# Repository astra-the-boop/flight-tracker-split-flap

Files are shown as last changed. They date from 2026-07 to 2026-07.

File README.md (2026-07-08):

# Split flap flight-tracker display
---
## Images
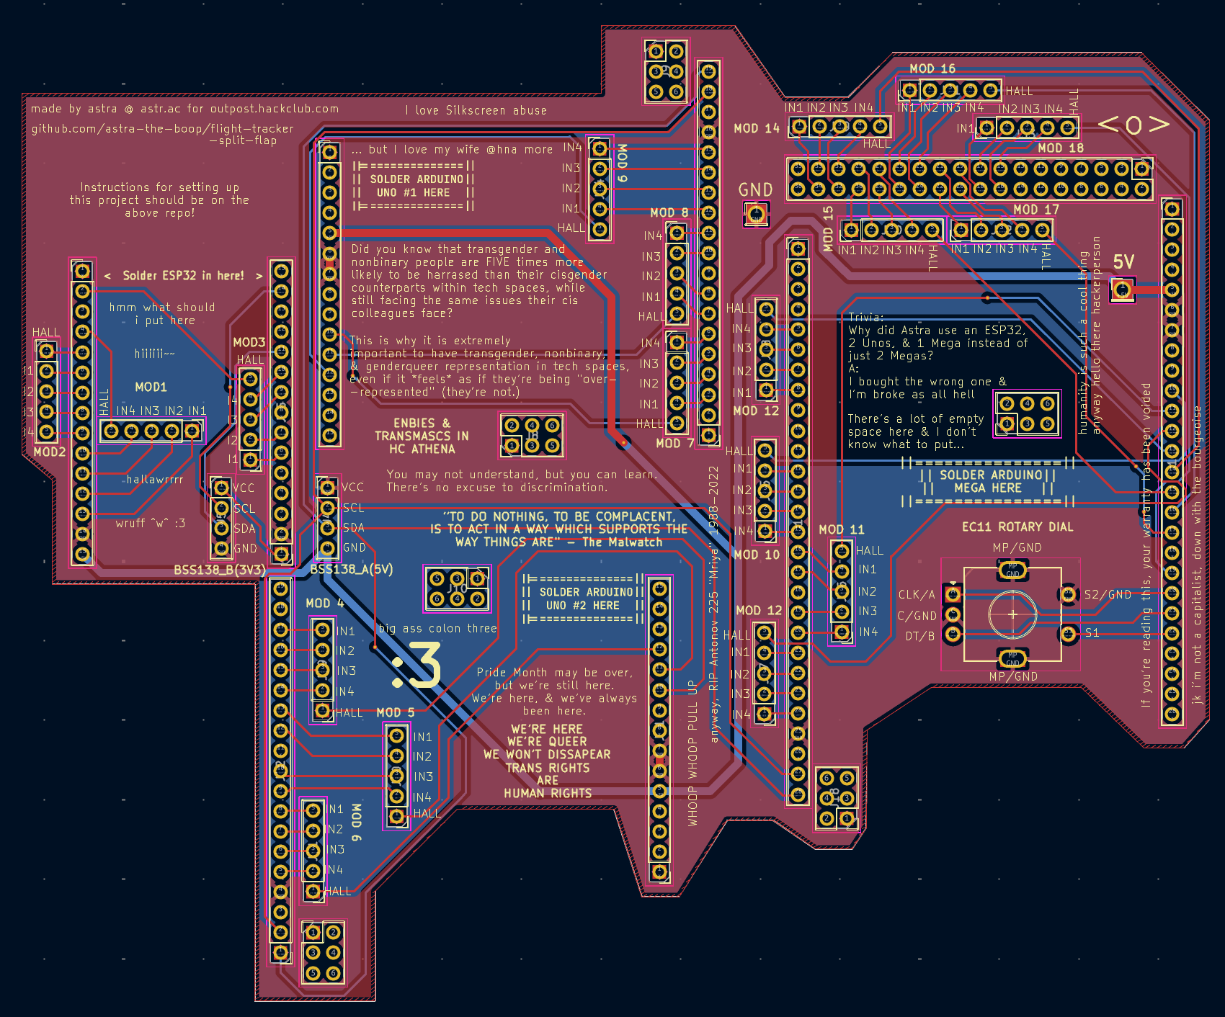
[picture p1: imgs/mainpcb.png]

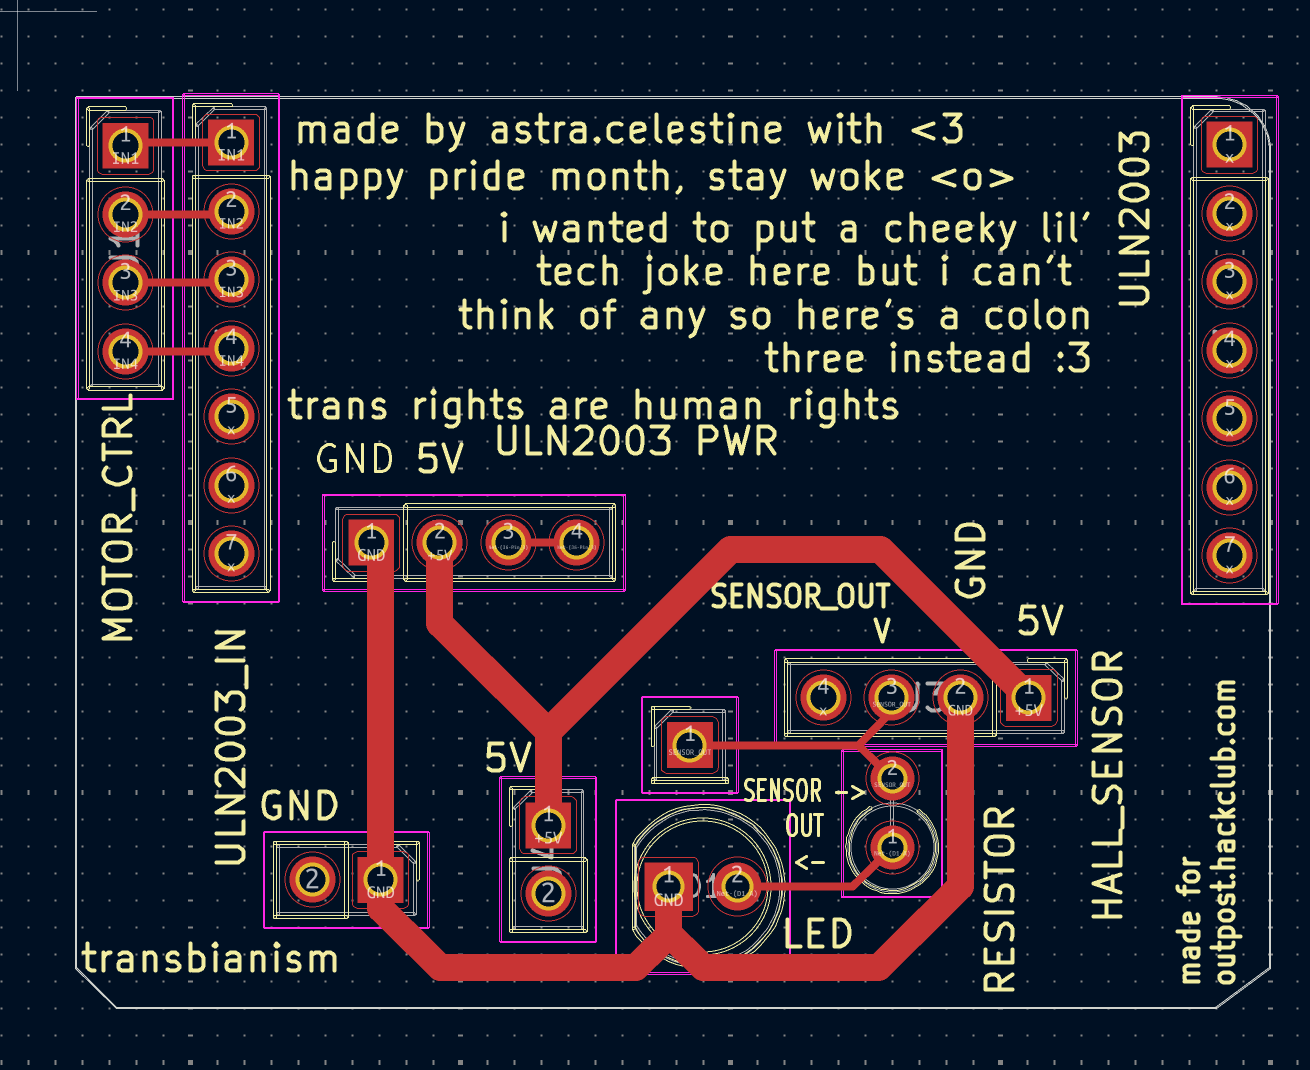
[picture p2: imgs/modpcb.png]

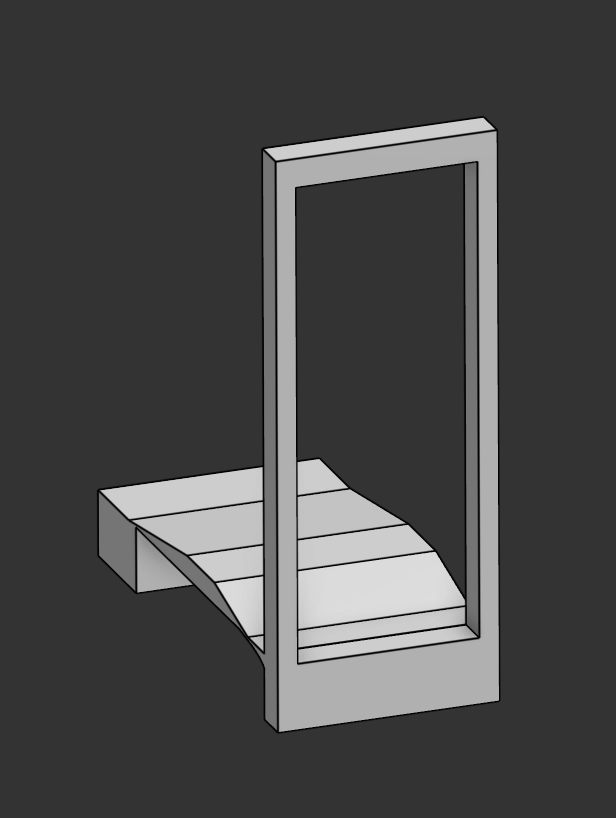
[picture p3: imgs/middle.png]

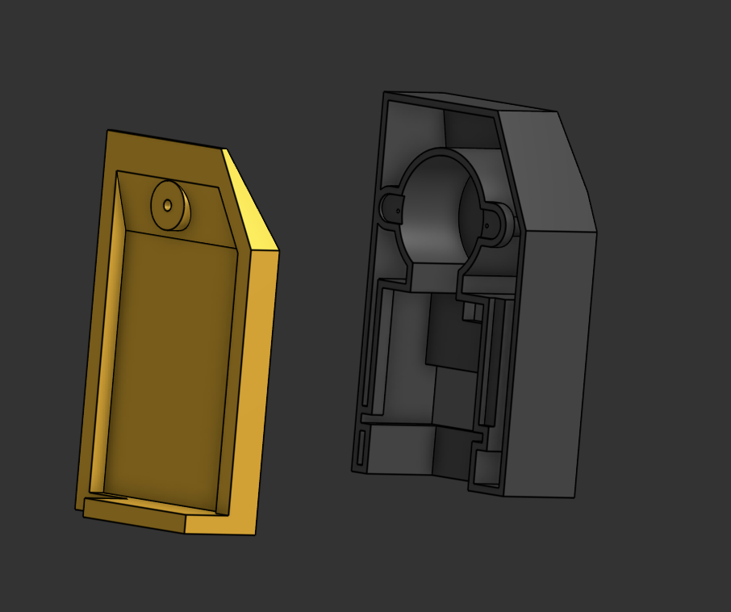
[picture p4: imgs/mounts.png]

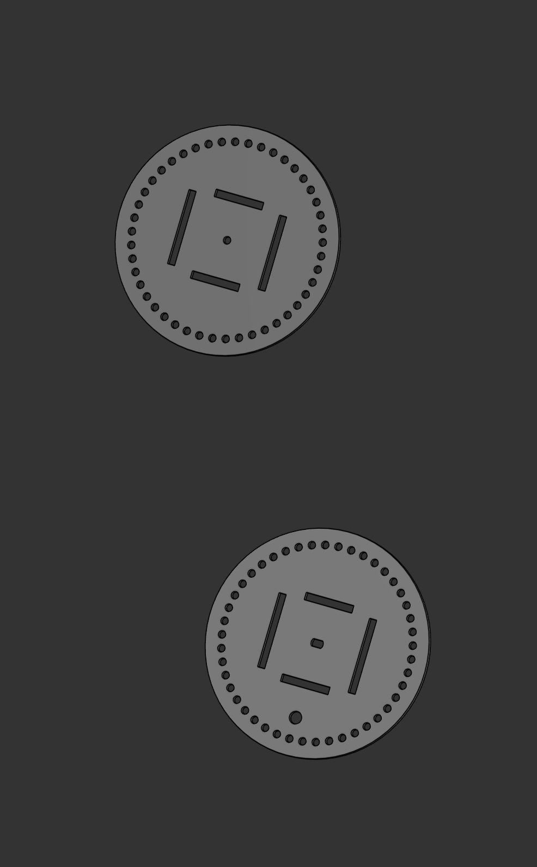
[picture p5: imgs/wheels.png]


## Whots this UwU?
It's a split flap display with 18 characters designed to show just enough info to track flights. It uses an ESP32 to send API requests to [AviationStack](https://docs.apilayer.com/aviationstack/docs/api-documentation) (oof, only 100 req/mo), and displays the info accordingly.

The display has 3 rows, the first row has 7 characters (1 showing logos, 2 showing airline IATA code, 4 showing flight number), the 2nd row has 6 characters showing the origin and destination airport, the 3rd row has 5 alphanumeric characters and shows flight status (INFLT, DELAY, CNCLD, BRDNG), or time (23:59, 5 DAYS, 5 HRS, 3H49M, etc) which could be configured to different modes (only show status, only show time, or switch between the two).

Each character is its own module and can function independently with 45 character positions each, and the PCB designs makes this simple to do. Each module also includes a magnet and a hall effect sensor for calibration.

## Dimensions
Each module by itself is 9cm wide, up to 14.5cm tall, and up to 10cm thick.
The entire system is 64.3cm wide, 47cm tall, and 15cm thick.

## CAD & PCB
This was designed in Onshape and KiCad.

## Other details:
This uses 1 ESP32 DevKit v1, 2 Arduino Unos, and 1 Arduino Mega. This is not the best way to do it, I only did this because I'm dead broke and that's what i had.
This project uses the MIT License.

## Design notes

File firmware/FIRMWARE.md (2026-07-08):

# Firmware
> ## Waiting to complete firmware code until I have the required hardware so this is completely untested, but here's a complete rundown of the code's logic:

## Module level:
The module has 4 input pins (INPUT1-4) relevant for controlling the motors. It also has 1 Hall effect sensor output pin, and a 5V and GND pin connected to the power supply (irrelevant to code).



Modules 1-3 is controlled and connected to the ESP32
Modules 4-6 is controlled by Arduino Uno 1, 7-9 is controlled by Uno 2.
Modules 10-18 are controlled by the Arduino Mega.

Where the 5 pins are connected to and where each module should be soldered to are labeled on the Main PCB's silkscreen (MOD*), (HALL is the hall effect sensor's input, IN1-4 is INPUT1-4).



## Retrieving data
The ESP32 sends RESTful GET requests to [AviationStack](https://aviationstack.com/)'s [/v1/timetable](https://docs.apilayer.com/aviationstack/docs/aviationstack-api-v-1-0-0#/default/getFlightSchedule) endpoint for the saved flight code. (Note: Free version is limited to 100 req/mo)
This uses the HTTPClient library (dependencies: Wifi.h, HTTPClient.h, WifiClientSecure.h, ArduinoJson.h)

## Parsing
As shown in README.md, there's 18 characters.
Char 1 (Logo): Have a set array of up to 44 of your most likely to be used airlines' IATA code (e.g. "CX"). From response["data"]["airline"]["iataCode"], search for that IATA code from the array, if found, return the index, else return 0 (blank).
Char 2 (IATA): response["data"]["airline"]["iataCode"][0]
Char 3: response["data"]["airline"]["iataCode"][1]
Char 4 (flight code): response["data"]["flight"]["number"][0]
Char 5-7: response["data"][... ...][1-3]
Char 8-10: response["data"]["departure"]["iataCode"][0-2]
Char 11-13: response...["arrival"][...][0-2]
Char 14-18: 
In case of showing time: response...["departure"]["scheduledTime"].substring(11,16) or response...["arrival"]... in if flight is already in air.
In case of showing flight status: Have 2 arrays of different statuses and the shortened version (e.g. ["boarding", "delayed", ...] ["BRDNG", "DELAY", ...]. Get response...["status"], get index of it in the first array, get the value of that index at the 2nd array.

Parse the value of that string substringed [0-5]

## Displaying
For the modules directly connected to the ESP32, the ESP32 uses AccelStepper to control the motors' position, movement, and acceleration. AccelStepper allows for simultanious commands while the default Stepper lib only allows for async execution.
The motor shall rotate until the hall effect sensor sends a signal (using INPUT_PULLUP), which then sets the index to 0. There shall be an array of characters (e.g. [BLANK/DEFAULT, A, B, C, ..., 8, 9, 0, -, :, " ", ...]) with 45 items, program starts a for loop until it reaches the desired character, for each loop, the motor rotates by 8º (AccelStepper allows for motor control by degrees), and increases the counter by 1.

For modules that aren't connected directly to the ESP32, the ESP32 shall send the desired character to be displayed to the Arduino Unos or Mega via I²C, and then it does the above.

## Input
There's a rotary encoder switch on the Arduino Mega, so the Mega shall receive input from the rotary encoder switch via INPUT_PULLUP, and relay it back to the ESP32 via I²C.
On the ESP32's memory, there shall be a string variable which represents the flight code.
By default, the displays show nothing, and the current mode is set to read only.
When a signal is received from the rotary encoder's CLK pin, Arduino mega starts a timer until it's released, if it's longer than 1500ms, then it relays a signal to the ESP32 to change to edit mode.
In edit mode, there is an index (pointer) variable set at 0 (representing flightCode[0] (the string we set earlier)). Rotating the encoder clockwise moves the value of the chracter of which the pointer is pointing to is set to the next item (or loops over to [0] if it's [-1]) of the array of characters we set earlier (blank, A-Z, 1-9, 0, special characters). Vice versa for counterclockwise. The motor moves 8º (or -8º for ccw) without checking for hall effect sensor homing.
Receiving a single click would move it to the next pointer position (or in case of [4], moves to [0]), a single click is a click where the timer ends <1500ms.
Once in edit mode and a long click (≥1500m) happens, all characters in flightCode.substr(2, 4) that is not either blank or an integer is replaced with '0' and if it's blank, it's replaced with '', and reformatted after such that it's a 4 digit number (e.g. 12 -> 0012). After which, a regular display reload would occur as described previously (i.e. does a rotation until sensor detects magnet, then rotate 8º until reaches the desired character). An API request to AviationStack would then be made and data is saved to request variable. After which it goes through the process of refreshing, requesting, parsing, and displaying as previously displayed.

## Refreshing
3 variables are set for the data refresh rates, one for 90 minutes until scheduled flight, one for 9 hours until scheduled flights, and one for all before that. (Would've just had everything at a really short refresh time if not for the fact that you only get like 100 FUCKING REQUESTS A MONTH FOR SOME REASON. IT'S THE BEST FUCKING OPTION TOO EVERYTHING ELSE IS PAID)
Just does a loop with the set time where each loop goes through the fetch-~~decode-execute~~parse-display cycle.

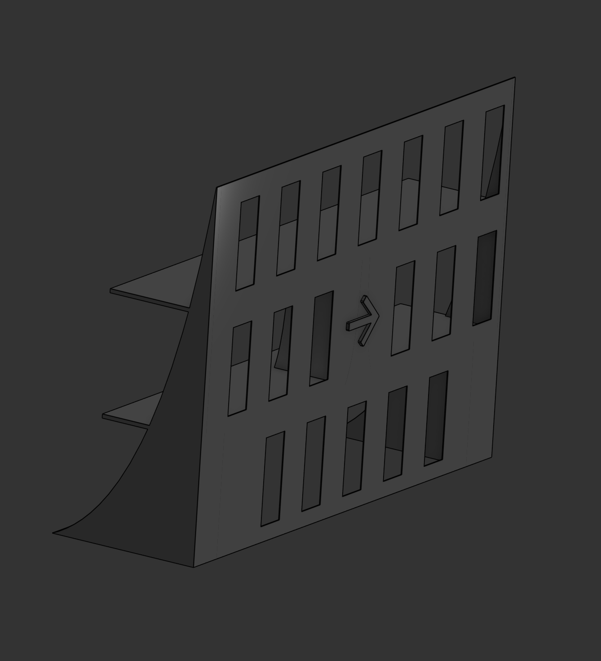
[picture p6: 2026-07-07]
imgs/shell.png

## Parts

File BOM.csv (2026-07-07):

Part | Qty | Price per pc VND | Price per pc USD | Total price USD | Link | Notes | SECTION
5V 28BYJ-48 Stepper motor + ULN2003 Module | 18 | 50,000 ₫ | $1.90 | $34.23 | https://vn.shp.ee/5EBNqvki |  | Modules
A3144 V1 Hall effect sensor MODULE | 18 | 25,000 ₫ | $0.95 | $17.12 | https://vn.shp.ee/HDDp57As
PCB | 1 | 300,000 ₫ | $11.41 | $11.41 |  | for all 18 modules (actually 25, they manufacturer gave me extra for some reason)
3D printing motor mount | 767.52 | 500 ₫ | $0.02 | $14.60 |  | per gram
3D printing wheel motor side | 252 | 500 ₫ | $0.02 | $4.79 |  | per gram
3D printing wheel right side | 261 | 500 ₫ | $0.02 | $4.96 |  | per gram
3D printing wheel connector 1+4 | 212.4 | 500 ₫ | $0.02 | $4.04 |  | per gram
3D printing wheel connector 2+3 | 293.76 | 500 ₫ | $0.02 | $5.59 |  | per gram
3D printing right side mount | 840.96 | 500 ₫ | $0.02 | $15.99 |  | per gram
3D printing centerpiece | 918 | 500 ₫ | $0.02 | $17.46 |  | per gram
2mm x Ø5mm Nd magnet (10pc) | 2 | 50,000 ₫ | $1.90 | $3.80 | https://vn.shp.ee/khDsGHYL
LEDs | 18 | 1,000 ₫ | $0.04 | $0.68
Resistor | 1 | 36,000 ₫ | $1.37 | $1.37 | https://vn.shp.ee/Kp1muEma
PCB | 1 | 440,000 ₫ | $16.74 | $16.74 |  |  | Main
5V/10A Power supply | 1 | 122,000 ₫ | $4.64 | $4.64
ESP32 | 1 | 136,000 ₫ | $5.17 | $5.17
Arduino Uno | 2 | 201,000 ₫ | $7.64 | $15.29 | https://vn.shp.ee/dqiFtsHQ
Arduino Mega | 1 | 280,000 ₫ | $10.65 | $10.65 | https://lkcg.vn/arduino-mega2560-ch340g-tang-kem-cap
EC11 Rotary Encoder Switch | 1 | 14,000 ₫ | $0.53 | $0.53 | https://banlinhkien.com/cong-tac-vo-cap-ec11-p6648261.html
BSS138 voltage thingy | 1 | 40,000 ₫ | $1.52 | $1.52 | https://hshop.vn/mach-chuyen-muc-ton-hieu-2-chieu-8-kenh | Including shipping
 |  |  | $0.00 | $0.00

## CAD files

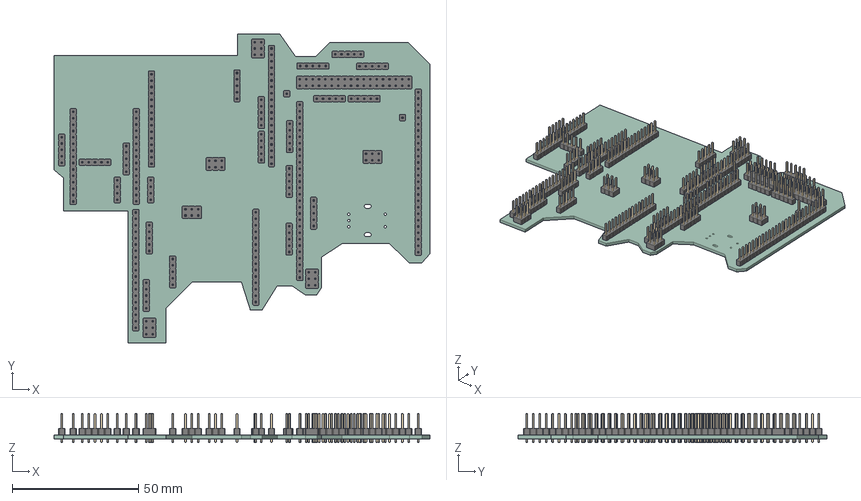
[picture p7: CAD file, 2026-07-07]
PCB/Main board.step
149.2 x 122.6 x 11.5 mm
PinHeader_1x05_P2.54mm_Vertical x 18
PinHeader_1x15_P2.54mm_Vertical x 4
PinHeader_1x19_P2.54mm_Vertical x 2
PinHeader_2x03_P2.54mm_Vertical x 6
PinHeader_1x04_P2.54mm_Vertical x 2
PinHeader_1x26_P2.54mm_Vertical
PinHeader_2x18_P2.54mm_Vertical
PinHeader_1x28_P2.54mm_Vertical
PinHeader_1x01_P2.54mm_Vertical x 2
outpost split flap esp32_PCB

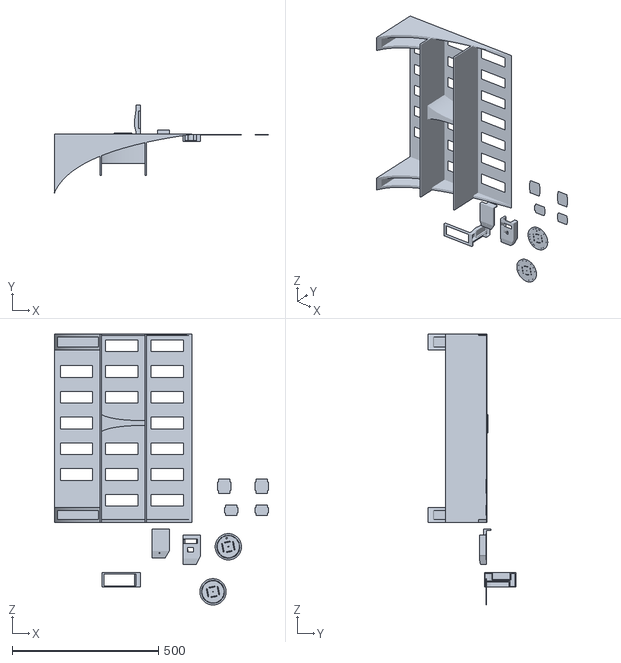
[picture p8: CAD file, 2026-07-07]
CAD/CAD.stl
731.2 x 300.0 x 925.5

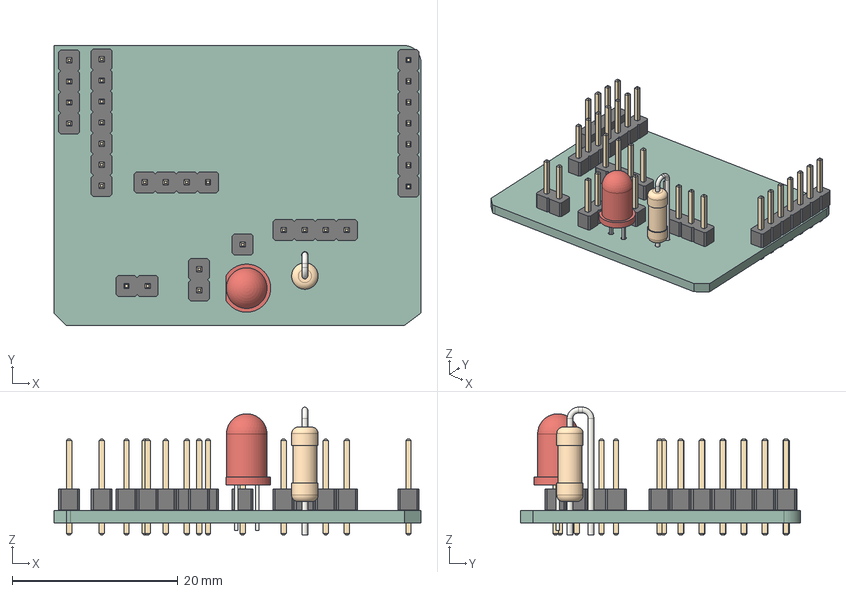
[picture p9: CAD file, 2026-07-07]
PCB/Module board.step
44.2 x 33.8 x 15.4 mm
PinHeader_1x04_P2.54mm_Vertical x 3
PinHeader_1x02_P2.54mm_Vertical x 2
R_Axial_DIN0309_L9.0mm_D3.2mm_P2.54mm_Vertical
LED_D5.0mm
PinHeader_1x07_P2.54mm_Vertical x 2
PinHeader_1x01_P2.54mm_Vertical
outpost split flap thing_PCB

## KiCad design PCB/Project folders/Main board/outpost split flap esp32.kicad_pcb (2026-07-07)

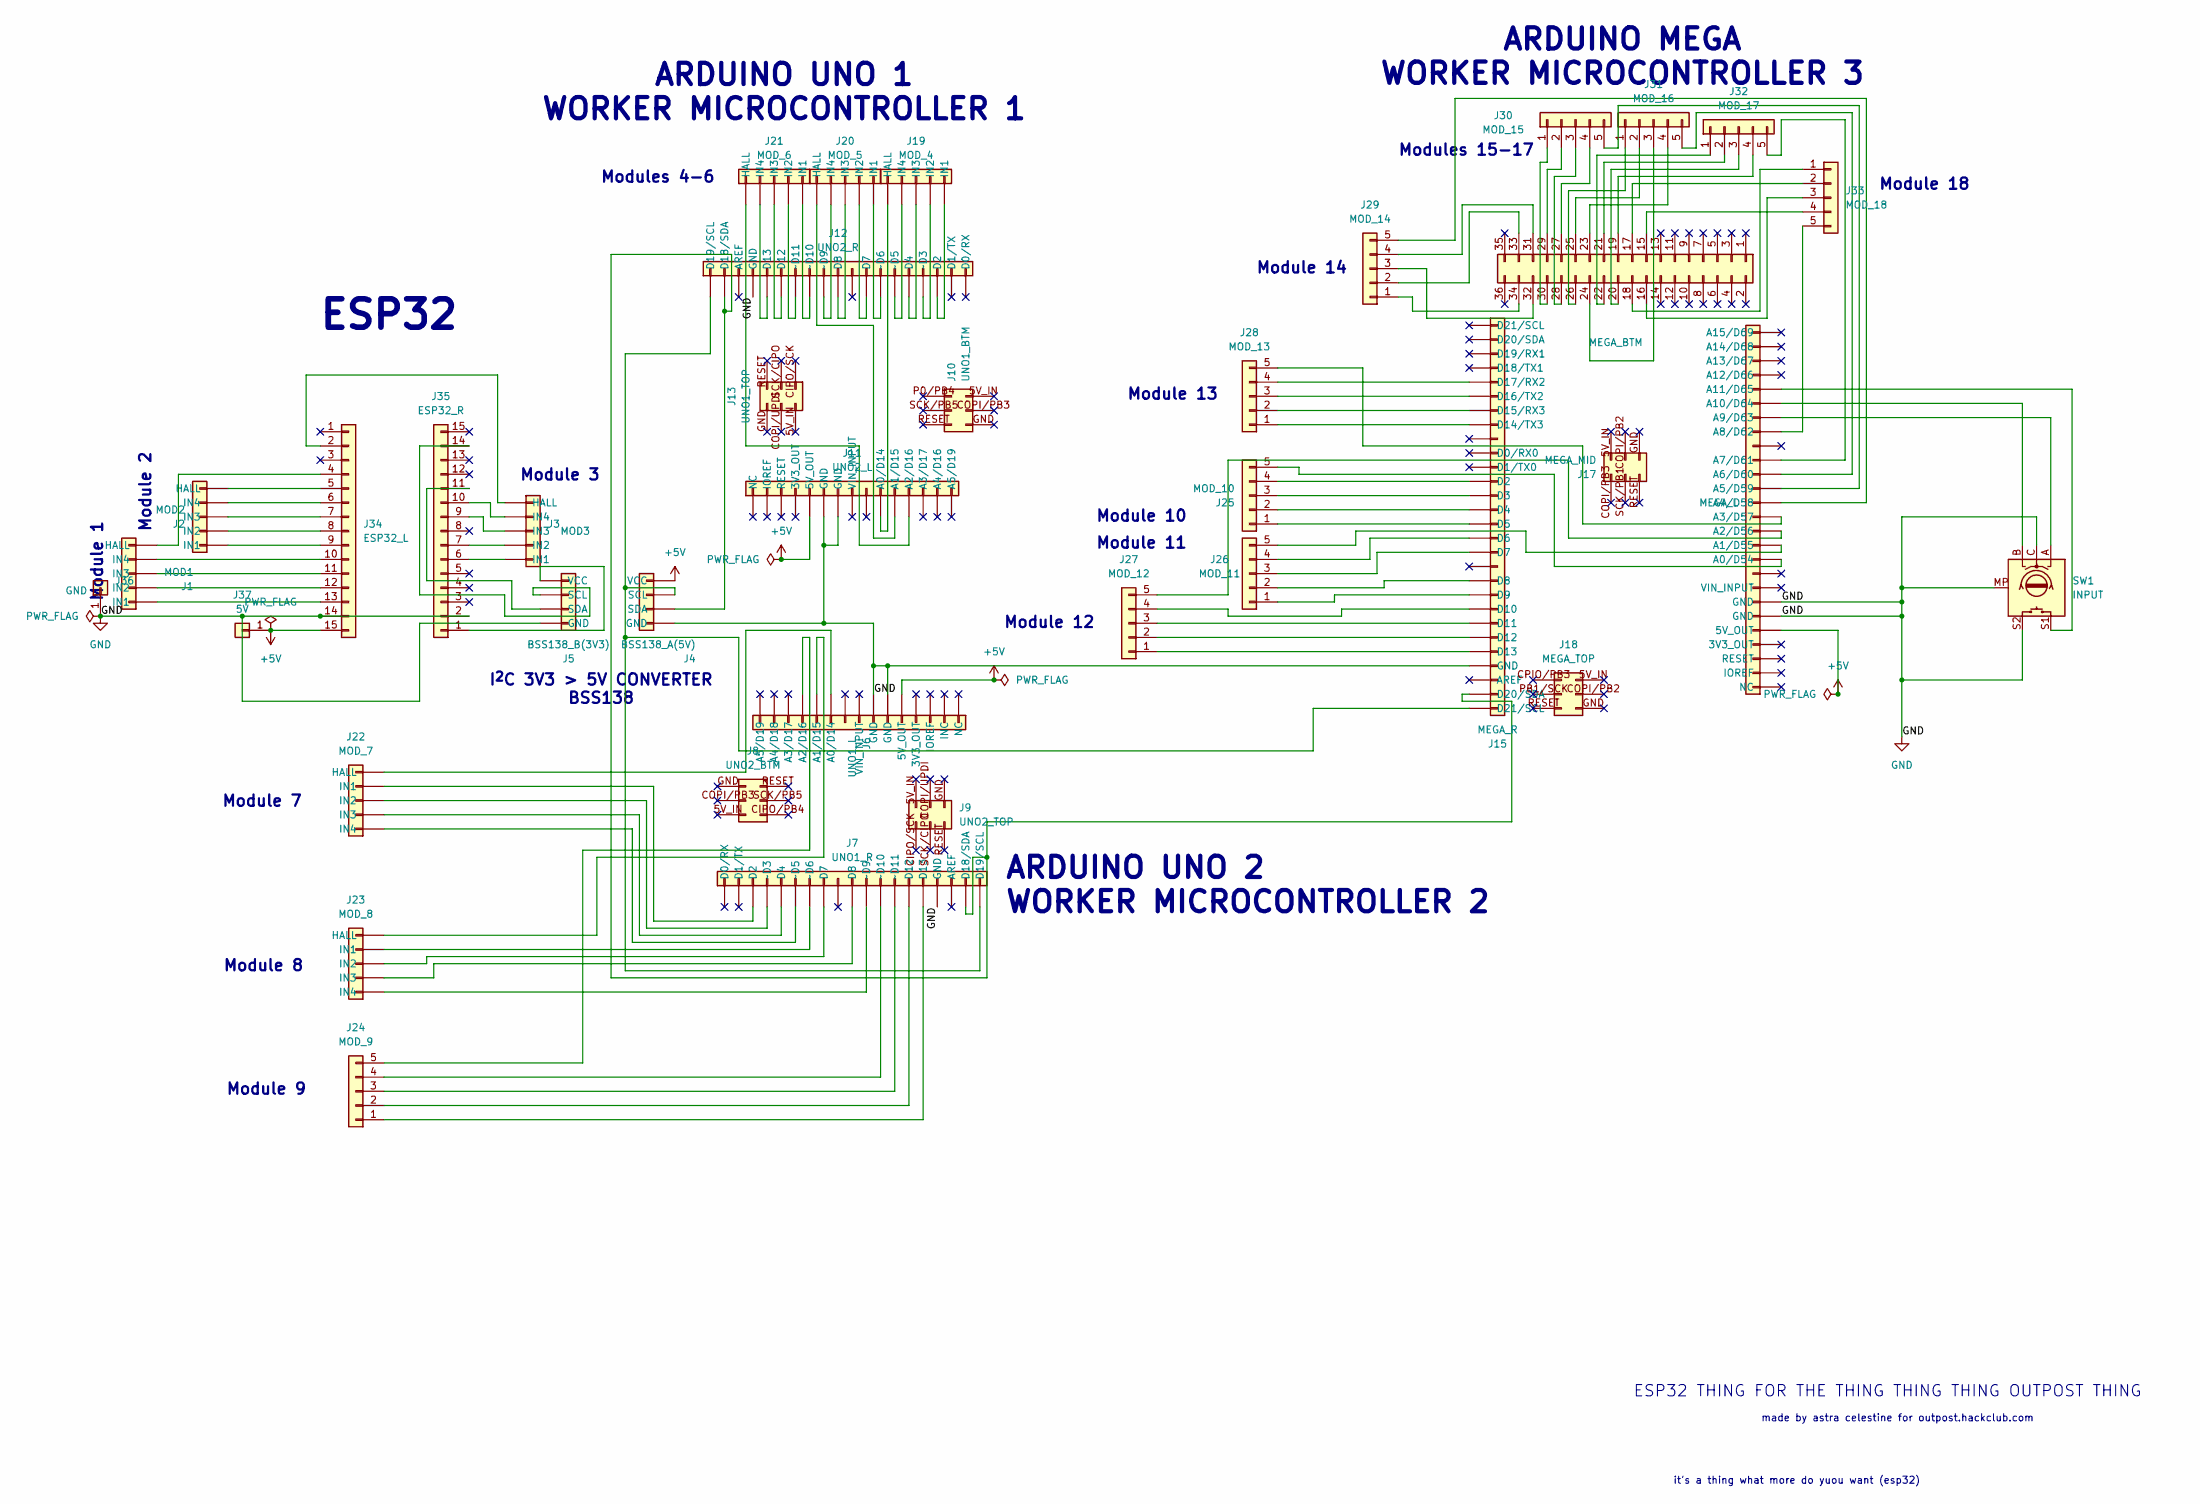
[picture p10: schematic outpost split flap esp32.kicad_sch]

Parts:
J1: MOD1; PinHeader_1x05_P2.54mm_Vertical
J2: MOD2; PinHeader_1x05_P2.54mm_Vertical
J3: MOD3; PinHeader_1x05_P2.54mm_Vertical
J4: BSS138_A(5V); PinHeader_1x04_P2.54mm_Vertical
J5: BSS138_B(3V3); PinHeader_1x04_P2.54mm_Vertical
J6: UNO1_L; PinHeader_1x15_P2.54mm_Vertical
J7: UNO1_R; PinHeader_1x19_P2.54mm_Vertical
J8: UNO2_BTM; PinHeader_2x03_P2.54mm_Vertical
J9: UNO2_TOP; PinHeader_2x03_P2.54mm_Vertical
J10: UNO1_BTM; PinHeader_2x03_P2.54mm_Vertical
J11: UNO2_L; PinHeader_1x15_P2.54mm_Vertical
J12: UNO2_R; PinHeader_1x19_P2.54mm_Vertical
J13: UNO1_TOP; PinHeader_2x03_P2.54mm_Vertical
J14: MEGA_L; PinHeader_1x26_P2.54mm_Vertical
J15: MEGA_R; PinHeader_1x28_P2.54mm_Vertical
J16: MEGA_BTM; PinHeader_2x18_P2.54mm_Vertical
J17: MEGA_MID; PinHeader_2x03_P2.54mm_Vertical
J18: MEGA_TOP; PinHeader_2x03_P2.54mm_Vertical
J19: MOD_4; PinHeader_1x05_P2.54mm_Vertical
J20: MOD_5; PinHeader_1x05_P2.54mm_Vertical
J21: MOD_6; PinHeader_1x05_P2.54mm_Vertical
J22: MOD_7; PinHeader_1x05_P2.54mm_Vertical
J23: MOD_8; PinHeader_1x05_P2.54mm_Vertical
J24: MOD_9; PinHeader_1x05_P2.54mm_Vertical
J25: MOD_10; PinHeader_1x05_P2.54mm_Vertical
J26: MOD_11; PinHeader_1x05_P2.54mm_Vertical
J27: MOD_12; PinHeader_1x05_P2.54mm_Vertical
J28: MOD_13; PinHeader_1x05_P2.54mm_Vertical
J29: MOD_14; PinHeader_1x05_P2.54mm_Vertical
J30: MOD_15; PinHeader_1x05_P2.54mm_Vertical
J31: MOD_16; PinHeader_1x05_P2.54mm_Vertical
J32: MOD_17; PinHeader_1x05_P2.54mm_Vertical
J33: MOD_18; PinHeader_1x05_P2.54mm_Vertical
J34: ESP32_L; PinHeader_1x15_P2.54mm_Vertical
J35: ESP32_R; PinHeader_1x15_P2.54mm_Vertical
J36: GND; PinHeader_1x01_P2.54mm_Vertical
J37: 5V; PinHeader_1x01_P2.54mm_Vertical
SW1: INPUT; RotaryEncoder_Alps_EC11E-Switch_Vertical_H20mm

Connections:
+5V: J4.4 (VCC), J6.5 (5V_OUT), J11.5 (5V_OUT), J14.5 (5V_OUT), J34.15, J37.1
GND: J4.1 (GND), J5.4 (GND), J6.6 (GND), J6.7 (GND), J7.16 (GND), J11.6 (GND), J11.7 (GND), J12.4 (GND), J14.6 (GND), J14.7 (GND), J15.25 (GND), J34.14, J35.2, J36.1, SW1.C, SW1.MP, SW1.S2
unnamed: J1.5 (HALL), J34.4
unnamed: J1.1 (IN1), J34.13
unnamed: J1.2 (IN2), J34.12
unnamed: J1.3 (IN3), J34.11
unnamed: J1.4 (IN4), J34.10
unnamed: J2.1 (HALL), J34.5
unnamed: J2.5 (IN1), J34.9
unnamed: J2.4 (IN2), J34.8
unnamed: J2.3 (IN3), J34.7
unnamed: J2.2 (IN4), J34.6
unnamed: J3.5 (HALL), J34.2
unnamed: J3.1 (IN1), J35.6
unnamed: J3.2 (IN2), J35.7
unnamed: J3.3 (IN3), J35.9
unnamed: J3.4 (IN4), J35.10
unnamed: J11.10 (A0/D14), J19.1 (HALL)
unnamed: J11.11 (A1/D15), J20.1 (HALL)
unnamed: J11.12 (A2/D16), J21.1 (HALL)
unnamed: J12.17 (D2), J19.5 (IN1)
unnamed: J12.15 (D4), J19.3 (IN3)
unnamed: J12.12 (D7), J20.4 (IN2)
unnamed: J12.10 (D8), J20.3 (IN3)
unnamed: J12.6 (D12), J21.3 (IN3)
unnamed: J12.5 (D13), J21.2 (IN4)
unnamed: J4.2 (SDA), J7.18 (D18/SDA), J12.2 (D18/SDA), J15.27 (D20/SDA)
unnamed: J4.3 (SCL), J7.19 (D19/SCL), J12.1 (D19/SCL), J15.28 (D21/SCL)
unnamed: J12.16 (~D3), J19.4 (IN2)
unnamed: J12.14 (~D5), J19.2 (IN4)
unnamed: J12.13 (~D6), J20.5 (IN1)
unnamed: J12.9 (~D9), J20.2 (IN4)
unnamed: J12.8 (~D10), J21.5 (IN1)
unnamed: J12.7 (~D11), J21.4 (IN2)
unnamed: J14.10 (A0/D54), J25.5 (HALL)
unnamed: J14.11 (A1/D55), J26.5 (HALL)
unnamed: J14.12 (A2/D56), J27.5 (HALL)
unnamed: J14.13 (A3/D57), J28.5 (HALL)
unnamed: J14.14 (A4/D58), J29.5 (HALL)
unnamed: J14.15 (A5/D59), J30.5 (HALL)
unnamed: J14.16 (A6/D60), J31.5 (HALL)
unnamed: J14.17 (A7/D61), J32.5 (HALL)
unnamed: J14.19 (A8/D62), J33.5 (HALL)
unnamed: J14.20 (A9/D63), SW1.A
unnamed: J14.21 (A10/D64), SW1.B
unnamed: J14.22 (A11/D65), SW1.S1
unnamed: J15.12 (D2), J25.4 (IN1)
unnamed: J15.13 (D3), J25.3 (IN2)
unnamed: J15.14 (D4), J25.2 (IN3)
unnamed: J15.15 (D5), J25.1 (IN4)
unnamed: J15.16 (D6), J26.4 (IN1)
unnamed: J15.17 (D7), J26.3 (IN2)
unnamed: J15.19 (D8), J26.2 (IN3)
unnamed: J15.20 (D9), J26.1 (IN4)
unnamed: J15.21 (D10), J27.4 (IN1)
unnamed: J15.22 (D11), J27.3 (IN2)
unnamed: J15.23 (D12), J27.2 (IN3)
unnamed: J15.24 (D13), J27.1 (IN4)
unnamed: J15.8 (D14/TX3), J28.1 (IN1)
unnamed: J15.7 (D15/RX3), J28.2 (IN2)
unnamed: J15.6 (D16/TX2), J28.3 (IN3)
unnamed: J15.5 (D17/RX2), J28.4 (IN4)
unnamed: J16.34 (D22), J29.1 (IN1)
unnamed: J16.33 (D23), J29.2 (IN2)
unnamed: J16.32 (D24), J29.3 (IN3)
unnamed: J16.31 (D25), J29.4 (IN4)
unnamed: J16.30 (D26), J30.1 (IN1)
unnamed: J16.29 (D27), J30.2 (IN2)
unnamed: J16.28 (D28), J30.3 (IN3)
unnamed: J16.27 (D29), J30.4 (IN4)
unnamed: J16.26 (D30), J31.1 (IN1)
unnamed: J16.25 (D31), J31.2 (IN2)
unnamed: J16.24 (D32), J31.3 (IN3)
unnamed: J16.23 (D33), J31.4 (IN4)
unnamed: J16.22 (D34), J32.1 (IN1)
unnamed: J16.21 (D35), J32.2 (IN2)
unnamed: J16.20 (D36), J32.3 (IN3)
unnamed: J16.19 (D37), J32.4 (IN4)
unnamed: J16.18 (D38), J33.1 (IN1)
unnamed: J16.17 (D39), J33.2 (IN2)
unnamed: J16.16 (D40), J33.3 (IN3)
unnamed: J16.15 (D41), J33.4 (IN4)
unnamed: J6.10 (A0/D14), J22.5 (HALL)
unnamed: J7.3 (D2), J22.4 (IN1)
unnamed: J7.4 (~D3), J22.3 (IN2)
unnamed: J7.5 (D4), J22.2 (IN3)
unnamed: J7.6 (~D5), J22.1 (IN4)
unnamed: J6.11 (A1/D15), J23.5 (HALL)
unnamed: J7.7 (~D6), J23.4 (IN1)
unnamed: J7.8 (D7), J23.3 (IN2)
unnamed: J7.10 (D8), J23.2 (IN3)
unnamed: J7.11 (~D9), J23.1 (IN4)
unnamed: J6.12 (A2/D16), J24.5 (HALL)
unnamed: J7.12 (~D10), J24.4 (IN1)
unnamed: J7.13 (~D11), J24.3 (IN2)
unnamed: J7.14 (D12), J24.2 (IN3)
unnamed: J7.15 (D13), J24.1 (IN4)
unnamed: J5.1 (VCC), J35.1
unnamed: J5.3 (SDA), J35.11
unnamed: J5.2 (SCL), J35.14

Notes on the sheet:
Modules 4-6
Module 13
Module 3
Module 18
it's a thing what more do yuou want (esp32)
Module 10
ESP32 THING FOR THE THING THING THING OUTPOST THING
I^{2}C 3V3 > 5V CONVERTER BSS138
Modules 15-17
Module 11
ARDUINO MEGA WORKER MICROCONTROLLER 3
Module 8
Module 7
Module 1
Module 12
ESP32
ARDUINO UNO 2 WORKER MICROCONTROLLER 2
Module 14
made by astra celestine for outpost.hackclub.com
ARDUINO UNO 1 WORKER MICROCONTROLLER 1
Module 9
Module 2

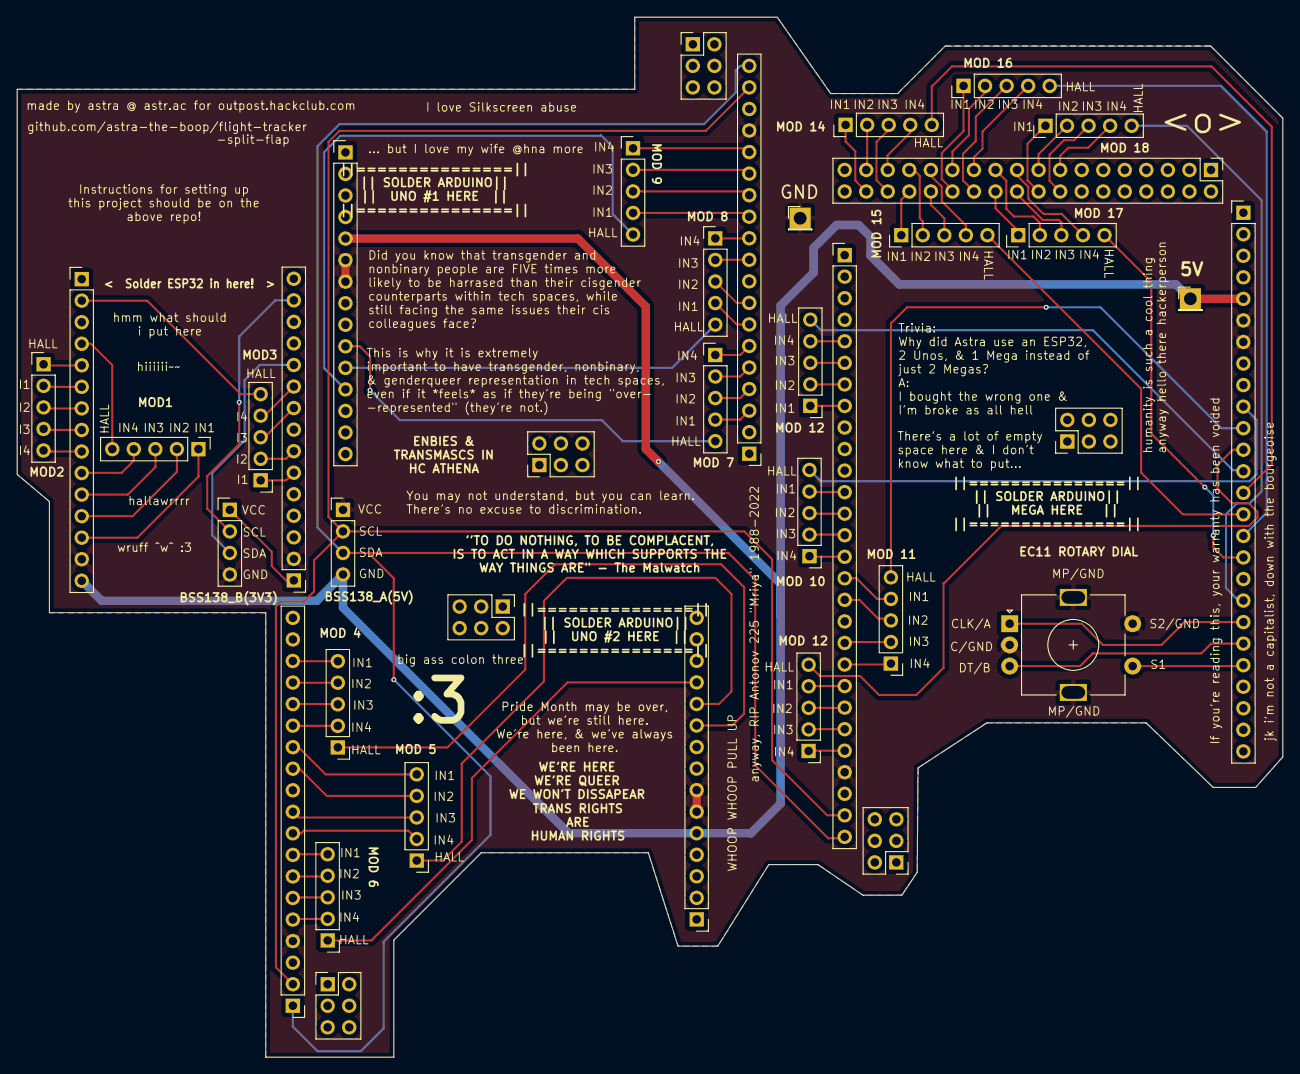
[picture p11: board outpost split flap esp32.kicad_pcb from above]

Board: 2 copper layers, 149.2 x 122.6 mm, 38 parts (0 on the bottom side), 100 nets.

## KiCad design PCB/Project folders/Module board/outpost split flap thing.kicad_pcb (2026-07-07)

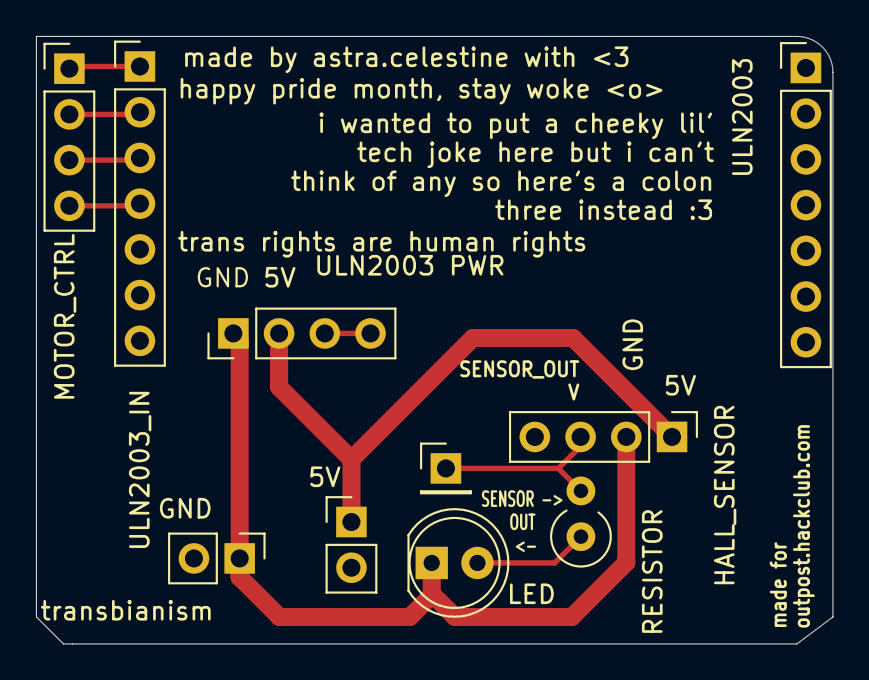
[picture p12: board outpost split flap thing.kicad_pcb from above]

Board: 2 copper layers, 44.2 x 33.8 mm, 10 parts (0 on the bottom side), 9 nets.

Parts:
D1: LED; LED_D5.0mm
J1: MOTOR_CTRL; PinHeader_1x04_P2.54mm_Vertical
J2: SENSOR_OUT; PinHeader_1x01_P2.54mm_Vertical
J3: HALL_SENSOR; PinHeader_1x04_P2.54mm_Vertical
J4: 5V; PinHeader_1x02_P2.54mm_Vertical
J5: ULN2003_IN; PinHeader_1x07_P2.54mm_Vertical
J6: ULN2003 PWR; PinHeader_1x04_P2.54mm_Vertical
J7: ULN2003; PinHeader_1x07_P2.54mm_Vertical
J8: GND; PinHeader_1x02_P2.54mm_Vertical
R1: RESISTOR; R_Axial_DIN0309_L9.0mm_D3.2mm_P2.54mm_Vertical

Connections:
+5V: J3.1, J4.1, J6.2
/IN1: J1.1, J5.1
/IN2: J1.2, J5.2
/IN3: J1.3, J5.3
/IN4: J1.4, J5.4
/SENSOR_OUT: J2.1, J3.3, R1.2
GND: D1.1 (K), J3.2, J6.1, J8.1
unnamed: D1.2 (A), R1.1
unnamed: J6.3, J6.4

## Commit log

2026-07-07 type shit
    [CAD.stl, Main board.step, Module board.step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]
2026-07-07 aaa so tired
